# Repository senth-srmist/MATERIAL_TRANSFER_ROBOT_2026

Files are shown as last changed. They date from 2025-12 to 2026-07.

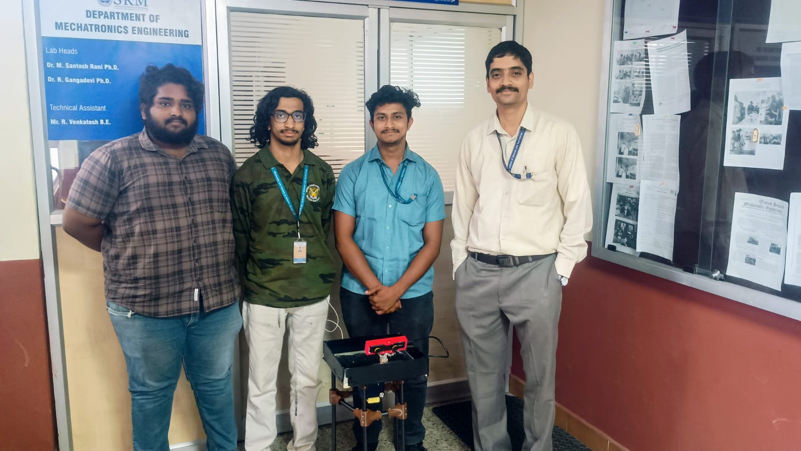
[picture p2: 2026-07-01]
WhatsApp Image 2026-05-07 at 16.34.46.jpeg

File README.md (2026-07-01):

# Floor-Level Material Transfer Mobile Robot

This repository contains the software for the **development of an autonomous floor-level material transfer mobile robot**.
The system is designed to operate within a **single indoor floor environment**, autonomously transporting materials between designated pickup and drop-off points (such as room entrances), while safely coexisting with human activity.

The project aims to establish a **validated core platform for indoor autonomous logistics**, integrating navigation, task handling, and human-aware operation. It serves as a foundation for scalable deployment across larger indoor environments such as offices, academic buildings, and hospitals.

> **Note:** A detailed description of the project motivation, objectives, system architecture, methodology, and deliverables is available in the project presentation:  
> https://github.com/senth-srmist/MATERIAL_TRANSFER_ROBOT_2026/blob/main/REVIEWS/Zeroth_Review/Presentation.pptx

---

## Repository Setup

### 1. Clone the repository

```bash
git clone https://github.com/senth-srmist/MATERIAL_TRANSFER_ROBOT_2026.git
cd MATERIAL_TRANSFER_ROBOT_2026
```

---

### 2. Initialize and update top-level submodules

This repository uses Git submodules for managing external dependencies.

```bash
git submodule update --init --recursive
```

---

## ZED Wrapper Setup

The `zed_wrapper` submodule requires **platform-specific versioning**.
Incorrect versions may lead to build or runtime failures.

### Navigate to the ZED wrapper

```bash
cd CODE/ros_ws/src/zed_wrapper
```

### ZED Wrapper Version Selection

The ZED wrapper **must** be set to version **humble-v4.0.8** for compatibility.

```bash
git checkout humble-v4.2.5
```

---

### Update submodules inside `zed_wrapper`

```bash
git submodule update --init --recursive
```

---

### Verify the selected version

```bash
git describe --tags
```

---

## Updating the Repository

Whenever pulling new changes, ensure submodules are kept in sync:

```bash
git pull
git submodule update --init --recursive
```

---

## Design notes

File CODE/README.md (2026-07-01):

# Material Transfer Robot - Docker Setup

## Prerequisites

> **Note:** Skip step 2 and 3 if your device does not have NVIDIA graphics.

### 1. Check Docker Version

```bash
docker --version
# Must be >= 20.x
```

### 2. Install NVIDIA Container Toolkit

```bash
distribution=$(. /etc/os-release; echo $ID$VERSION_ID)
curl -fsSL https://nvidia.github.io/libnvidia-container/gpgkey | sudo gpg --dearmor -o /usr/share/keyrings/nvidia-container-toolkit-keyring.gpg
curl -s -L "https://nvidia.github.io/libnvidia-container/${distribution}/libnvidia-container.list" -o /tmp/nvidia-container.list
sed -i 's#deb https://#deb [signed-by=/usr/share/keyrings/nvidia-container-toolkit-keyring.gpg] https://#g' /tmp/nvidia-container.list
sudo mv /tmp/nvidia-container.list /etc/apt/sources.list.d/nvidia-container-toolkit.list
sudo apt-get update
sudo apt-get install -y nvidia-container-toolkit
sudo nvidia-ctk runtime configure --runtime=docker
sudo systemctl restart docker
```

### 3. Install ZED udev rules on the host

```bash
sudo mv CODE/99-slabs.rules /etc/udev/rules.d/99-slabs.rules
sudo chmod 644 /etc/udev/rules.d/99-slabs.rules
sudo udevadm control --reload-rules
sudo udevadm trigger
```

## Build Dev Container

> **Note:** The base image is pre-built and hosted on GitHub Container Registry
> (`ghcr.io/tejasmk-tkp/material-transfer-robot-base-{amd64|arm64}:latest`).
> It will be pulled automatically during build — no manual setup needed.

```bash
# amd64 (Laptop)
TARGETARCH=amd64 docker compose build

# arm64 (Jetson)
TARGETARCH=arm64 docker-compose build
```

## Start and Run the Container

```bash
xhost +local:docker
```

### ROS2 Communication Modes

| Mode | Description | Network | Use Case |
| --- | --- | --- | --- |
| local | Localhost only | No | Single-device operation |
| network | Full cross-device DDS | Yes | Multi-device ROS2 (high bandwidth) |
| viz | Throttled remote rviz | Yes | Remote visualization (low bandwidth) |

### Local Mode (Default)

```bash
docker compose up -d

# arm64 (Jetson)
docker-compose -f docker-compose.yml -f docker-compose.arm64.yml up -d
```

### Network Mode

```bash
ROS_MODE=network CYCLONE_INTERFACE_IP=<YOUR_IP> docker compose up -d

# arm64 (Jetson)
ROS_MODE=network CYCLONE_INTERFACE_IP=<YOUR_IP> docker-compose -f docker-compose.yml -f docker-compose.arm64.yml up -d
```

### Viz Mode (Remote RViz)

Run rviz on your laptop with minimal WiFi load. Robot stays local. A bridge forwards selected topics at throttled rates.

**On the Robot (Jetson):**

```bash
CYCLONE_INTERFACE_IP=<YOUR_IP> docker-compose -f docker-compose.yml -f docker-compose.arm64.yml -f docker-compose.viz.yml up -d material-transfer-robot viz-bridge
```

**On the Laptop:**

```bash
CYCLONE_INTERFACE_IP=<YOUR_IP> docker compose -f docker-compose.yml -f docker-compose.viz.yml up viz-laptop
```

RViz auto-launches. Default config: `/workspace/rviz/viz.rviz`

**Custom rviz config:**

```bash
CYCLONE_INTERFACE_IP=<YOUR_IP> RVIZ_CONFIG=/workspace/rviz/nav.rviz docker compose -f docker-compose.yml -f docker-compose.viz.yml up viz-laptop
```

**Customizing topics:** Edit `viz_bridge_config.yaml`, then `docker-compose restart viz-bridge`.

**Stopping:**

```bash
# Laptop
docker compose -f docker-compose.yml -f docker-compose.viz.yml stop viz-laptop

# Robot
docker-compose -f docker-compose.yml -f docker-compose.arm64.yml -f docker-compose.viz.yml down
```

### Access Container

```bash
docker exec -it material-transfer-robot-container bash
```

### Stop Container

```bash
docker compose down
```

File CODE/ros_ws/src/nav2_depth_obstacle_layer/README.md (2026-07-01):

# nav2_depth_obstacle_layer

A Nav2 costmap layer plugin that projects depth image points as obstacles with optional human detection masking. Also provides BehaviorTree nodes for human-aware navigation.

## Overview

### Costmap Layer

Projects depth images onto the costmap as `LETHAL_OBSTACLE`. Points are filtered by height above ground to exclude floor and overhead obstacles.

**Human Detection Masking (Optional):** When enabled with ZED camera messages, regions containing detected humans are excluded from obstacle marking. This allows the BT nodes to handle human encounters (stop and wait) without triggering path replanning.

### BT Nodes

- **HumanBlockingPath**: Condition node that returns SUCCESS when a human is blocking the planned path within `human_stop_distance` of the robot.
- **WaitUntilHumanClears**: Action node that stops the robot and waits until the human moves away, optionally calling a speech service.

## Costmap Layer Parameters

| Parameter | Type | Default | Description |
|---|---|---|---|
| `depth_topic` | string | `/depth/image_rect` | Depth image topic |
| `camera_info_topic` | string | `/depth/camera_info` | Camera info topic |
| `ground_frame` | string | `base_link` | Frame for height calculation |
| `stride` | int | `2` | Pixel stride for processing |
| `obstacle_range` | double | `3.0` | Maximum range in meters |
| `min_obstacle_height` | double | `0.05` | Minimum height above ground (m) |
| `max_obstacle_height` | double | `1.5` | Maximum height above ground (m) |
| `human_mask_enabled` | bool | `false` | Enable human detection masking |
| `human_topic` | string | `""` | Human detection topic (ZED objects) |
| `human_mask_padding` | int | `20` | Padding around human bbox (pixels) |
| `human_persistence` | double | `0.5` | Time to keep human detection (s) |

## BT Node Ports

### HumanBlockingPath

| Port | Type | Default | Description |
|---|---|---|---|
| `path` | input | - | Current navigation path |
| `human_stop_distance` | input | `1.5` | Only stop if human within this distance (m) |
| `path_width` | input | `0.3` | Human must be within this of path (m) |
| `human_topic` | input | `/zed/zed_node/obj_det/objects` | Human detection topic |
| `global_frame` | input | `map` | Global frame |
| `robot_frame` | input | `base_link` | Robot frame |

### WaitUntilHumanClears

| Port | Type | Default | Description |
|---|---|---|---|
| `path` | input | - | Current navigation path |
| `human_stop_distance` | input | `1.5` | Distance threshold (m) |
| `path_width` | input | `0.3` | Path corridor width (m) |
| `human_topic` | input | `/zed/zed_node/obj_det/objects` | Human detection topic |
| `cmd_vel_topic` | input | `/cmd_vel` | Velocity command topic |
| `speak_service` | input | `/speak` | Speech service (empty to disable) |
| `speak_interval` | input | `5.0` | Seconds between announcements |

## Usage

### nav2_params.yaml

```yaml
local_costmap:
  local_costmap:
    ros__parameters:
      plugins: ["depth_obstacle_layer", "inflation_layer"]

      depth_obstacle_layer:
        plugin: "nav2_depth_obstacle_layer::DepthObstacleLayer"
        enabled: true
        depth_topic: "/zed/zed_node/depth/depth_registered"
        camera_info_topic: "/zed/zed_node/depth/camera_info"
        ground_frame: "ground"
        stride: 2
        obstacle_range: 3.0
        min_obstacle_height: 0.05
        max_obstacle_height: 1.5
        human_mask_enabled: true
        human_topic: "/zed/zed_node/obj_det/objects"
        human_mask_padding: 20
        human_persistence: 0.5

bt_navigator:
  ros__parameters:
    plugin_lib_names:
      - nav2_depth_obstacle_layer_bt_nodes
      # ... other plugins

controller_server:
  ros__parameters:
    progress_checker:
      movement_time_allowance: 86400.0  # 24hr - allows indefinite human wait
```

### BT XML

```xml
<ReactiveSequence>
  <Inverter>
    <Sequence>
      <HumanBlockingPath path="{path}" human_stop_distance="1.5"/>
      <WaitUntilHumanClears path="{path}" speak_service="/speak"/>
    </Sequence>
  </Inverter>
  <FollowPath path="{path}"/>
</ReactiveSequence>
```

## Building

```bash
colcon build --packages-select nav2_depth_obstacle_layer
```

The build automatically detects if `zed_msgs` is available. Without it:
- Costmap layer works but human masking is disabled
- BT nodes will not function (return FAILURE)

## Libraries

- `nav2_depth_obstacle_layer` - Costmap layer plugin
- `nav2_depth_obstacle_layer_bt_nodes` - BT nodes plugin

## License

Apache-2.0

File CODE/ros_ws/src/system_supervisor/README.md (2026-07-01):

# System Supervisor

Health monitoring and lifecycle management for the Material Transfer Robot. Manages always-on node monitoring, on-demand navigation stack startup/shutdown, categorized failure recovery, lifecycle-aware shutdown, dependent health checks, and system resource tracking.

## State Machine

```
                    ┌──────────────────────────────────────────────┐
                    │                                              │
  ┌─────────┐   all ready   ┌──────┐  nav_needed  ┌────────────┐ │ all up  ┌────────┐
  │ BOOTING ├──────────────►│ IDLE ├─────────────►│ ACTIVATING ├─┼────────►│ ACTIVE │
  └─────────┘               └──┬───┘              └─────┬───────┘ │        └───┬────┘
                               │  ▲                     │         │            │
                               │  │    abort/fail       │         │  !nav_needed
                               │  └─────────────────────┘         │            │
                               │  ▲                               │  ┌─────────▼──────┐
                               │  └───────────────────────────────┼──┤ DEACTIVATING   │
                               │                                  │  └────────────────┘
                               │          cat3 cascade            │
                               └──────────────────────────────────┘
```

**BOOTING** — Waits for all always-on nodes to come up. Uses progress-based detection. A 60-second boot delay prevents the supervisor from ticking before other nodes have had time to spawn, avoiding CPU/memory pressure on startup. Publishes `/system/ready` when all always-on nodes are RUNNING, then transitions to IDLE.

**IDLE** — All always-on nodes monitored. Waiting for `/system/nav_needed` from the job manager. When a delivery job arrives, transitions to ACTIVATING.

**ACTIVATING** — Starts on-demand nodes sequentially with health gates: ZED → odom_bridge → Nav2 → pid_controller → mission. Each node must pass its health check before the next starts. If any node fails, aborts activation, cleans up, and returns to IDLE.

**ACTIVE** — Full monitoring of all nodes. Categorized failure recovery runs here. Publishes `/system/nav_ready` on entry. Transitions to DEACTIVATING when nav is no longer needed.

**DEACTIVATING** — Shuts down on-demand nodes in reverse order: mission → pid_controller → Nav2 → odom_bridge → ZED. Publishes `/system/nav_shutdown` before stopping nodes. Returns to IDLE.

## Boot Detection

The supervisor uses progress-based detection rather than fixed boot timeouts. Each node tracks a `last_progress` timestamp that resets when milestones are hit:

- **PID found** — Process is at least running (resets stall timer)
- **Heartbeat received** — Node is fully operational (boot complete)

Two thresholds per node:

- `stall_timeout` — No progress for this many seconds means the node is stuck
- `max_boot_timeout` — Absolute safety net regardless of progress

For `pid_only` nodes, PID appearing is sufficient — no heartbeat topic required.

## Node Categories

Each monitored node has a failure category that determines recovery behavior:

**Category 1 (Auto Restart)** — Automatically restarts the node up to `max_restarts` times with a cooldown between attempts. Used for always-on nodes like motors, teleop, and encoders.

**Category 2 (Abort + Restart)** — Sends an e-stop command, then restarts the node. Used for navigation-critical nodes like Nav2, PID controller, and mission controller. If max restarts exhausted, marks system as DEGRADED and disables autonomous operation.

**Category 3 (Cascade Shutdown)** — Sends e-stop, kills all on-demand nodes, publishes nav_shutdown, and returns to IDLE. Used for localization-critical nodes like ZED camera and odom bridge. Losing these means localization is gone — no point keeping Nav2 running.

## Unit Mode

Nodes can be configured as units — atomic groups of processes that are monitored and managed together. If ANY process in a unit dies, the entire unit is restarted.

```yaml
nav2:
  unit: true
  process_names:
    - "controller_server"
    - "planner_server"
    - "bt_navigator"
    - "behavior_server"
    - "smoother_server"
    - "velocity_smoother"
    - "waypoint_follower"
    - "lifecycle_manager_navigation"
```

Unit mode is useful for tightly-coupled node groups like Nav2 where individual node restarts would leave the system in an inconsistent state.

## Lifecycle-Aware Shutdown

For ROS2 lifecycle-managed nodes, the supervisor attempts graceful shutdown before hard-killing processes:

```
Node needs restart
    │
    ├─► Is lifecycle_manager alive?
    │       │
    │       └─► YES: Call shutdown service (deactivate → cleanup → shutdown)
    │               Wait up to lifecycle_timeout seconds
    │
    ├─► Hard kill all processes (SIGTERM → SIGKILL)
    │
    ├─► Cleanup residues (pkill -9 for all process names)
    │
    └─► Verify all processes are dead
```

Configure lifecycle management per node:

```yaml
map_server:
  lifecycle_manager: "lifecycle_manager_map"
  lifecycle_timeout: 2.0
```

The supervisor calls `/{lifecycle_manager}/manage_nodes` with `{command: 2}` (shutdown) to gracefully transition managed nodes through their lifecycle states before hard-killing.

## Dependent Health Checks

When a node restarts, its downstream dependents may be left in a broken state (stale subscriptions, lost connections). The supervisor can automatically check and restart unhealthy dependents:

```yaml
zed:
  dependents: ["odom_bridge"]
  dependent_check_delay: 2.0

map_server:
  dependents: ["nav2"]
  dependent_check_delay: 3.0
```

After a node reaches RUNNING state:
1. Wait `dependent_check_delay` seconds for dependents to react
2. Check each dependent's health (status, heartbeat age)
3. Restart any unhealthy dependents
4. Cascade: restarted dependents will check their own dependents

Race condition guards prevent multiple restart attempts:
- Skip if dependent is already RESTARTING
- Skip if dependent was recently restarted (within cooldown)

## Dynamic Args

Nodes can specify arguments that are resolved at start/restart time by reading from files:

```yaml
map_server:
  start_cmd: ["ros2", "launch", "tile_manager", "map_server.launch.py"]
  dynamic_args:
    - "file:/tmp/current_tile.txt:map:=tile{}.yaml"
```

Format: `file:<filepath>:<format_string>`
- Reads content from `<filepath>`
- Strips whitespace
- Substitutes `{}` with the value
- Appends result to command

Example: If `/tmp/current_tile.txt` contains `3`, the command becomes:
```
ros2 launch tile_manager map_server.launch.py map:=tile3.yaml
```

This enables stateful restarts — the robot continues on the correct tile after a map_server crash.

## Always-On vs On-Demand Nodes

**Always-on** (monitored in all states, launched by robot_bringup):

| Node | Process | Detection | Category | Unit | Dependents |
|---|---|---|---|---|---|
| motors | motor_driver | PID only | Cat 1 | No | — |
| robot_description | robot_state_publisher | PID only | Cat 1 | No | — |
| map_server | map_server, lifecycle_manager_map | PID only | Cat 1 | Yes | nav2 |
| teleop | joy_node | PID only | Cat 1 | No | — |
| encoders | encoder_driver | PID only | Cat 1 | No | — |

**On-demand** (started/stopped by supervisor based on navigation need):

| Node | Process | Detection | Category | Unit | Dependents | Startup Order |
|---|---|---|---|---|---|---|
| zed | zed_wrapper | Topic: `/zed/zed_node/status/heartbeat` | Cat 3 | No | odom_bridge | 1 |
| odom_bridge | odom_base_publisher | Topic: `/odom/base_link` | Cat 3 | No | — | 2 |
| nav2 | (8 processes) | PID only | Cat 2 | Yes | — | 3 |
| pid_controller | pid_controller | PID only | Cat 2 | No | — | 4 |
| mission | mission_service | PID only | Cat 2 | No | — | 5 |

## Topics

### Published

| Topic | Type | QoS | Description |
|---|---|-----|---|
| `/robot_health` | `system_supervisor/RobotHealth` | RELIABLE, TRANSIENT_LOCAL, 1Hz | Full system status: per-node health, CPU, memory, supervisor state |
| `/system/ready` | `std_msgs/Empty` | RELIABLE, TRANSIENT_LOCAL, once | All always-on nodes are up — robot ready to accept jobs |
| `/system/nav_ready` | `std_msgs/Empty` | RELIABLE, TRANSIENT_LOCAL, on event | Nav stack activation complete |
| `/system/nav_shutdown` | `std_msgs/Empty` | RELIABLE, TRANSIENT_LOCAL, on event | Nav stack shutting down |
| `/cmd_vel_estop` | `geometry_msgs/Twist` | RELIABLE, VOLATILE | Emergency stop — zero velocity, routed through twist_mux at highest priority |

### Subscribed

| Topic | Type | QoS | Source |
|---|---|-----|---|
| `/system/nav_needed` | `std_msgs/Bool` | RELIABLE, TRANSIENT_LOCAL | job_manager — true when navigation stack is needed |
| Heartbeat topics | Configured per node | BEST_EFFORT, VOLATILE | Various — dynamic subscriptions from config |

## Messages

### RobotHealth.msg

```
std_msgs/Header header
float32 cpu_percent
uint8 cpu_count
float32 memory_used_mb
float32 memory_total_mb
system_supervisor/NodeHealth[] nodes
uint8 system_state
uint8 supervisor_state
string system_message
bool autonomous_enabled

uint8 NOMINAL=0
uint8 DEGRADED=1
uint8 LOCALIZATION_LOST=2
uint8 EMERGENCY_STOP=3

uint8 SV_BOOTING=0
uint8 SV_IDLE=1
uint8 SV_ACTIVATING=2
uint8 SV_ACTIVE=3
uint8 SV_DEACTIVATING=4
```

### NodeHealth.msg

```
string name
uint8 status
float32 cpu_percent
float32 memory_mb
float32 last_heartbeat_age
uint32 restart_count
uint32 error_count
string last_error
string message

uint8 WAITING=0
uint8 RUNNING=1
uint8 STALE=2
uint8 DEAD=3
uint8 RESTARTING=4
uint8 SHUTDOWN=5
uint8 OFF=6
```

## Configuration

All node definitions are in `config/supervisor_config.yaml`. The supervisor loads this at startup via the `config_file` parameter.

### Config Fields (per node)

| Field | Type | Default | Description |
|---|---|---|---|
| `category` | int | — | Failure category: 1, 2, or 3 |
| `process_name` | string | — | Process name for `pgrep` PID detection (single-process nodes) |
| `heartbeat_topic` | string | — | Topic to subscribe for liveness (omit for pid_only) |
| `heartbeat_msg_type` | string | — | Python message type string, e.g. `nav_msgs.msg.Odometry` |
| `pid_only` | bool | false | If true, PID detection is sufficient — no heartbeat needed |
| `stall_timeout` | float | 15.0 | Seconds without progress before declaring node stuck |
| `max_boot_timeout` | float | 120.0 | Absolute boot time limit |
| `heartbeat_timeout` | float | 3.0 | Seconds without heartbeat before STALE (running nodes) |
| `max_restarts` | int | 3 | Maximum restart attempts before giving up |
| `restart_cooldown` | float | 10.0 | Minimum seconds between restart attempts |
| `start_cmd` | list | — | Command to start the node |
| `dynamic_args` | list | [] | Arguments resolved at runtime from files |

### Unit Mode Fields

| Field | Type | Default | Description |
|---|---|---|---|
| `unit` | bool | false | Treat as atomic group of processes |
| `process_names` | list | [] | All process names in the unit (for monitoring and cleanup) |

### Lifecycle Management Fields

| Field | Type | Default | Description |
|---|---|---|---|
| `lifecycle_manager` | string | — | Name of lifecycle_manager node for graceful shutdown |
| `lifecycle_timeout` | float | 3.0 | Timeout for graceful lifecycle shutdown before hard kill |

### Dependency Management Fields

| Field | Type | Default | Description |
|---|---|---|---|
| `dependents` | list | [] | Node names to health-check after this node restarts |
| `dependent_check_delay` | float | 2.0 | Seconds to wait before checking dependent health |

### On-Demand Node Fields

| Field | Type | Description |
|---|---|---|
| `startup_order` | int | Sequence number for activation (lower starts first) |
| `wait_type` | string | `"topic"` or `"pid"` — what to wait for during activation |

## Resource Monitoring

The supervisor tracks system-wide and per-node resource usage at 0.5 Hz:

- **System CPU** — Read from `/proc/stat`, averaged across all cores
- **System Memory** — Read from `/proc/meminfo` (total and available)
- **Per-node CPU** — Read from `/proc/<pid>/stat` (user + system ticks)
- **Per-node Memory** — RSS from `/proc/<pid>/status`

All values are published in the `/robot_health` message.

## Parameters

| Parameter | Default | Description |
|---|---|---|
| `config_file` | (install path) | Path to supervisor_config.yaml |
| `boot_delay` | 60.0 | Seconds to wait after init before starting health checks |

## Package Structure

```
system_supervisor/
├── config/
│   └── supervisor_config.yaml
├── msg/
│   ├── NodeHealth.msg
│   └── RobotHealth.msg
└── system_supervisor/
    └── system_supervisor.py
```

## Monitoring

```bash
# Watch system health
ros2 topic echo /robot_health

# Wait for robot ready
ros2 topic echo /system/ready --once

# Check supervisor state only
ros2 topic echo /robot_health --field supervisor_state

# Check specific node status
ros2 topic echo /robot_health --field nodes | grep -A5 "name: nav2"
```

## Example Scenarios

### Scenario 1: ZED Camera Crash

```
ZED dies (heartbeat timeout)
    ↓
Category 3 → Cascade shutdown
    ↓
E-stop, kill all on-demand nodes
    ↓
Return to IDLE, await new job
```

### Scenario 2: Map Server Crash (with tile persistence)

```
map_server dies
    ↓
Supervisor reads /tmp/current_tile.txt → "3"
    ↓
Lifecycle shutdown of lifecycle_manager_map
    ↓
Hard kill map_server + lifecycle_manager_map
    ↓
Restart: ros2 launch tile_manager map_server.launch.py map:=tile3.yaml
    ↓
map_server reaches RUNNING
    ↓
Check dependents: nav2
    ↓
nav2 healthy? Continue. Unhealthy? Restart nav2 too.
```

### Scenario 3: Nav2 Controller Server Crash

```
controller_server dies (unit monitors all 8 processes)
    ↓
Unit check fails → entire nav2 unit marked DEAD
    ↓
Category 2 → E-stop + restart
    ↓
Lifecycle shutdown via lifecycle_manager_navigation
    ↓
Hard kill all 8 Nav2 processes
    ↓
Restart: ros2 launch robot_navigation navigation.launch.py
    ↓
All Nav2 nodes come up fresh with clean lifecycle state
```

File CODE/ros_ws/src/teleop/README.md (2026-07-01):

# Teleoperation with Game Controller (ROS 2)

This package enables **manual teleoperation of the robot using a game controller** via ROS 2.

It uses:

* `joy` → to read joystick input
* `teleop_twist_joy` → to convert joystick input into `/cmd_vel`

---
## Step 1: Start the joystick driver

This node reads raw joystick data and publishes it on `/joy`.

```bash
ros2 run joy joy_node
```

### Verify joystick input

In a new terminal:

```bash
ros2 topic echo /joy
```

You should see output like:

```yaml
axes:
- 0.0
- -0.4
buttons:
- 0
- 1
```

If axes/buttons change when you move the controller → **joystick is working**.

---

## Step 2: Start teleop (joystick → velocity)

This node converts `/joy` messages into `/cmd_vel` using a YAML config.

```bash
ros2 run teleop_twist_joy teleop_node \
  --ros-args \
  --params-file src/teleop/config/teleop.yaml
```
---

## Step 3: Verify velocity output

In another terminal:

```bash
ros2 topic echo /cmd_vel
```

Expected behavior:

* Hold the **deadman button** → `/cmd_vel` updates
* Release the deadman → `/cmd_vel` goes to zero
* Left stick forward/back → `linear.x`
* Left stick left/right → `angular.z`

---

## Control Mapping (Xbox-style)

| Control | Action |
| --- | --- |
| Left stick up/down | Forward / Backward (`linear.x`) |
| Left stick left/right | Turn Left / Right (`angular.z`) |
| Right bumper (RB) | Deadman (must be held to move)  |

---

## Useful Debug Commands

Check joystick data:

```bash
ros2 topic echo /joy
```

Check velocity commands:

```bash
ros2 topic echo /cmd_vel
```

Check running nodes:

```bash
ros2 node list
```
---

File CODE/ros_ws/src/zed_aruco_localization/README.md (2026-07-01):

# ZED ArUco Localization

ArUco marker-based localization and evaluation for ZED stereo cameras. Three tools in one package: generate printable markers, localize the camera at runtime, and evaluate marker performance under controlled conditions.

## Quick Start

```bash
# Generate markers
ros2 run zed_aruco_localization aruco_marker_generator --ros-args -p marker_size:=0.07

# Start ZED camera first (required)
ros2 launch zed_wrapper zed_camera.launch.py camera_model:=zedm

# Then run localization
ros2 launch zed_aruco_localization zed_aruco_loc.launch.py camera_model:=zedm

# Or run evaluation
ros2 launch zed_aruco_localization aruco_evaluation.launch.py
ros2 service call /start_evaluation zed_aruco_localization/srv/StartArucoEvaluation \
  "{distance_m: 2.0, angle_deg: 0.0, num_samples: 300}"
```

## Package Structure

```
zed_aruco_localization/
├── CMakeLists.txt
├── config/
│   └── aruco_loc.yaml              # Marker config (auto-generated + manual edits)
├── eval_metrics/
│   └── stats.csv                   # Evaluation results (auto-appended)
├── launch/
│   ├── aruco_evaluation.launch.py  # Evaluation pipeline
│   └── zed_aruco_loc.launch.py     # Runtime localization
├── markers/
│   └── 6x6_1000-0.png             # Generated marker images
├── rviz2/
│   └── aruco.rviz                  # RViz config for visualization
├── src/
│   ├── aruco_marker_eval.cpp       # Evaluation node
│   ├── aruco_marker_generator.cpp  # Marker generator node
│   ├── component/
│   │   ├── include/
│   │   │   ├── aruco.hpp
│   │   │   └── zed_aruco_localization_component.hpp
│   │   └── src/
│   │       ├── aruco.cpp
│   │       └── zed_aruco_localization_component.cpp
│   └── include/
│       └── aruco_loc_visibility_control.hpp
├── srv/
│   └── StartArucoEvaluation.srv
└── videos/
    └── aruco.mp4
```

## Prerequisites

The ZED camera must be running before launching the localization or evaluation nodes. Start it separately:

```bash
ros2 launch zed_wrapper zed_camera.launch.py camera_model:=zedm
```

The localization node subscribes to ZED image topics and calls ZED's `set_pose` service. If ZED is not running, the node will wait for topics and the service to become available.

## Dependencies

- OpenCV 4.x (core, imgproc, calib3d, aruco module)
- [zed-ros2-wrapper](https://github.com/stereolabs/zed-ros2-wrapper) (zed_wrapper, zed_components, zed_msgs)
- image_transport
- tf2, tf2_ros, tf2_geometry_msgs
- yaml-cpp

Supports all ZED camera models: zed, zedm, zed2, zed2i, zedx, zedxm.

## Nodes

### 1. Marker Generator (`aruco_marker_generator`)

Generates printable ArUco markers at real-world physical size and updates `aruco_loc.yaml` with marker definitions.

```bash
ros2 run zed_aruco_localization aruco_marker_generator --ros-args \
  -p marker_count:=3 \
  -p marker_size:=0.07 \
  -p dpi:=300
```

**Parameters:**

| Parameter | Default | Description |
|---|---|---|
| `marker_count` | 1 | Number of markers to generate (IDs: 0 to N-1) |
| `marker_size` | 0.07 | Physical marker size in meters |
| `dpi` | 300 | Print resolution |
| `output_format` | png | Output format (png, jpg, svg) |
| `maximum_distance` | 2.0 | Max detection distance in meters |
| `detection_rate` | 0.5 | Detection frequency in Hz |
| `camera_name` | zed | Camera namespace |
| `world_frame_id` | map | World frame for marker poses |
| `refine_detection` | false | Enable sub-pixel corner refinement |
| `debug_level` | 1 | 0=none, 1=markers, 2=full |

Markers are saved to `markers/` directory. Dictionary: `DICT_6X6_1000`.

> Use **image-magick** to display images at actual size. When printing, ensure scaling is set to 100% / "Actual Size".

### 2. Localization Node (`zed_aruco_loc_node`)

Detects ArUco markers in the ZED camera feed, estimates camera pose relative to known marker positions, and resets the ZED pose in the global map frame via the `set_pose` service. Runs as a composable node in its own container.

**Topics:**

| Direction | Topic | Type | Description |
|---|---|---|---|
| Subscribe | `<cam>/zed_node/rgb/color/rect/image` | sensor_msgs/Image | ZED rectified RGB image |
| Subscribe | `<cam>/zed_node/rgb/color/rect/camera_info` | sensor_msgs/CameraInfo | Camera intrinsics |
| Publish | `<cam>/aruco_node/out/aruco_result` | sensor_msgs/Image | Detection visualization |

**Services (client):**

| Service | Type | Description |
|---|---|---|
| `<cam>/zed_node/set_pose` | zed_msgs/SetPose | Resets ZED camera pose when marker detected |

**TF Broadcasts:**

| Parent Frame | Child Frame | Description |
|---|---|---|
| `<world_frame_id>` | `aruco_marker_<id>` | Known marker positions in world frame |

**Behavior:**
- Only the nearest valid marker within `maximum_distance` is used
- Pose estimation via `estimatePoseSingleMarkers`
- Detection frequency throttled by `detection_rate`
- Requires the `<camera_name>_left_camera_frame` → `<camera_name>_camera_link` TF (published by ZED's state publisher)

**Launch:**

```bash
# ZED must be running first
ros2 launch zed_aruco_localization zed_aruco_loc.launch.py camera_model:=zedm
```

**Launch Arguments:**

| Argument | Default | Description |
|---|---|---|
| `camera_model` | zedm | zed, zedm, zed2, zed2i, zedx, zedxm |
| `camera_name` | zed | Camera namespace |
| `aruco_node_name` | aruco_node | Name of the ArUco node |
| `config_path_aruco` | (package default) | Path to aruco_loc.yaml |
| `rviz` | true | Launch RViz with ArUco config |

### 3. Evaluation Node (`aruco_evaluation`)

Evaluates ArUco marker detection accuracy under controlled conditions. Idle by default — triggered via service call to collect pose statistics at a specific distance and angle.

This node does **not** reset pose, publish TF, or interfere with localization.

**Topics:**

| Direction | Topic | Type | Description |
|---|---|---|---|
| Subscribe | `/zed/zed_node/rgb/image_rect_color` | sensor_msgs/Image | ZED rectified RGB |
| Subscribe | (camera_info from same transport) | sensor_msgs/CameraInfo | Camera intrinsics |

**Services (server):**

| Service | Type | Description |
|---|---|---|
| `/start_evaluation` | StartArucoEvaluation | Start a measurement run |

**Service Request:**

| Field | Type | Description |
|---|---|---|
| `distance_m` | float32 | Physical distance between camera and marker |
| `angle_deg` | float32 | Viewing angle of marker |
| `num_samples` | int32 | Number of frames to process |

**Launch:**

```bash
# ZED must be running first
ros2 launch zed_aruco_localization aruco_evaluation.launch.py
ros2 launch zed_aruco_localization aruco_evaluation.launch.py camera_model:=zedm
```

**Computed Statistics (per run):**
- Mean and standard deviation of x, y, z, yaw
- Detection ratio (detections / attempted frames)
- Results appended to `eval_metrics/stats.csv`

**CSV Columns:**

```
timestamp, marker_size_m, distance_m, angle_deg, samples_collected,
frames_attempted, detection_ratio, mean_x_m, std_x_m, mean_y_m,
std_y_m, mean_z_m, std_z_m, mean_yaw_deg, std_yaw_deg
```

## Configuration

All parameters are loaded from `config/aruco_loc.yaml`. This file is auto-generated by the marker generator but can be edited manually.

```yaml
/**:
  ros__parameters:
    general:
      marker_count: 1
      marker_size: 0.030
      maximum_distance: 2.000
      detection_rate: 0.500
      camera_name: zed
      world_frame_id: map
      refine_detection: false
    debug:
      level: 1                          # 0=none, 1=markers, 2=full
    marker_000:
      aruco_id: 0
      position: [0.000, 0.000, 0.000]  # x, y, z in world frame
      orientation: [0.000, 0.000, 0.000] # roll, pitch, yaw in radians
```

> For every marker, update `position` and `orientation` with respect to the world frame to ensure correct localization. Default values are `[0, 0, 0]`.

## Evaluation Workflow

1. Print marker at target size using the generator
2. Mount marker flat on a wall
3. Place camera at a known distance and angle
4. Start ZED camera
5. Launch the evaluation node
6. Call the evaluation service with distance, angle, and sample count
7. Wait for completion — results are logged to terminal and CSV
8. Move to next configuration and repeat

Each service call produces one row in `eval_metrics/stats.csv`. The file is append-only, never overwritten.

## Integration Status

The localization node is planned for integration into the robot's production runtime via the system supervisor. Currently it runs standalone for testing and evaluation. Future integration will allow the supervisor to trigger ArUco-based relocalization on demand, for example after a ZED camera crash or localization drift.

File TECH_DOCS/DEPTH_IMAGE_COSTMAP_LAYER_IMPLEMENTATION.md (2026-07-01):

# DepthImageCostmapLayer Implementation Guide

## Background

Nav2's built-in `ObstacleLayer` in ROS2 Humble only supports `PointCloud2` and `LaserScan` — it does **not** support `DepthImage` directly. Our ZED camera produces a sparse point cloud even at maximum settings (VGA + COMPACT mode), but the depth map is dense and high quality.

Rather than using `depth_image_proc` to convert depth → PointCloud2 (adding ~50-100MB RAM and an extra node), we're building a custom Nav2 costmap layer plugin that directly consumes depth images.

### Why Custom Plugin?

| Approach | Memory | Latency | Control |
|---|---|---|---|
| `depth_image_proc` → ObstacleLayer | +50-100MB | Extra hop | None |
| **Custom DepthImageCostmapLayer** | Zero extra | Direct | Full (sampling, filtering) |

---

## Architecture

```
ZED Camera
    │
    ├── /zed/zed_node/depth/depth_registered (sensor_msgs/Image)
    │                           │
    │                           ▼
    │                   DepthImageCostmapLayer
    │                   ├── Subscribes to depth image
    │                   ├── Subscribes to obj_det/objects (human bboxes)
    │                   ├── MASKS OUT pixels inside human bounding boxes ◄── CRITICAL
    │                   ├── Samples remaining pixels at configurable stride
    │                   ├── Projects to 3D → transforms to map frame
    │                   └── Marks obstacles → Nav2 REPLANS AROUND them
    │
    ├── /zed/zed_node/depth/camera_info (sensor_msgs/CameraInfo)
    │
    └── /zed/zed_node/obj_det/objects (zed_msgs/ObjectsStamped)
                            │
                            ├──────────────────────────────────┐
                            │                                  │
                            ▼                                  ▼
                    HumanCostmapLayer                   DepthImageCostmapLayer
                    (marks humans)                      (uses bboxes to EXCLUDE humans)
                            │                                  │
                            ▼                                  ▼
                    BT: HumanBlockingPath              Nav2 Controller
                    → STOP + RAISE ALARM               → REPLAN + NAVIGATE
```

### Key Design: Separation of Concerns

| Obstacle Type | Detected By | Handled By | Nav2 Behavior |
|---|---|---|---|
| **Humans** | ZED obj_det | `HumanCostmapLayer` + BT | **STOP + ALARM** |
| **Everything else** | Depth image (masked) | `DepthImageCostmapLayer` | **REPLAN + NAVIGATE** |

**Why mask humans in depth layer?**
- If both layers mark humans → Nav2 might try to replan around a human
- We want humans to trigger STOP, not replanning
- Masking ensures clean separation of behavior

---

## Package Location

Add to existing `human_detection` package (or create new `depth_costmap_layer` package):

```
ros_ws/src/human_detection/
├── include/human_detection/
│   ├── human_costmap_layer.hpp       # Existing
│   └── depth_image_costmap_layer.hpp # NEW
├── src/
│   ├── human_costmap_layer.cpp       # Existing
│   └── depth_image_costmap_layer.cpp # NEW
├── human_costmap_layer_plugin.xml    # UPDATE (add new plugin)
├── CMakeLists.txt                    # UPDATE
└── package.xml                       # UPDATE (add image_geometry)
```

---

## Dependencies

Add to `package.xml`:

```xml
<depend>image_geometry</depend>
<depend>sensor_msgs</depend>
<depend>cv_bridge</depend>
```

Add to `CMakeLists.txt`:

```cmake
find_package(image_geometry REQUIRED)
find_package(sensor_msgs REQUIRED)
find_package(cv_bridge REQUIRED)

# Add to existing library or create new one
add_library(depth_image_costmap_layer SHARED
  src/depth_image_costmap_layer.cpp
)

ament_target_dependencies(depth_image_costmap_layer
  rclcpp
  nav2_costmap_2d
  pluginlib
  tf2_ros
  tf2_geometry_msgs
  geometry_msgs
  sensor_msgs
  image_geometry
  cv_bridge
)

pluginlib_export_plugin_description_file(nav2_costmap_2d depth_costmap_layer_plugin.xml)
```

---

## Header File

**`include/human_detection/depth_image_costmap_layer.hpp`**

```cpp
#ifndef DEPTH_IMAGE_COSTMAP_LAYER_HPP_
#define DEPTH_IMAGE_COSTMAP_LAYER_HPP_

#include "nav2_costmap_2d/layer.hpp"
#include "nav2_costmap_2d/layered_costmap.hpp"
#include "rclcpp/rclcpp.hpp"
#include "sensor_msgs/msg/image.hpp"
#include "sensor_msgs/msg/camera_info.hpp"
#include "image_geometry/pinhole_camera_model.h"
#include "tf2_ros/buffer.h"
#include "tf2_geometry_msgs/tf2_geometry_msgs.hpp"
#include "geometry_msgs/msg/point_stamped.hpp"
#include "zed_msgs/msg/objects_stamped.hpp"  // For human detection masking

#include <mutex>
#include <vector>
#include <string>

namespace human_detection
{

/**
 * @brief Nav2 costmap layer that directly consumes depth images
 * 
 * This plugin bypasses the need for PointCloud2 conversion by:
 * 1. Subscribing to depth image + camera_info
 * 2. Subscribing to ZED object detections to MASK OUT humans
 * 3. Sampling pixels at configurable stride (for performance)
 * 4. Skipping pixels inside human bounding boxes
 * 5. Projecting remaining pixels to 3D using camera intrinsics
 * 6. Transforming to global frame
 * 7. Marking/clearing costmap cells
 * 
 * IMPORTANT: Humans are handled by HumanCostmapLayer with STOP+ALARM behavior.
 * This layer handles all OTHER obstacles with AVOID+NAVIGATE behavior.
 * We must NOT mark humans here or Nav2 will try to replan around them.
 */
class DepthImageCostmapLayer : public nav2_costmap_2d::Layer
{
public:
  DepthImageCostmapLayer();
  virtual ~DepthImageCostmapLayer();

  // Nav2 Layer interface
  virtual void onInitialize() override;
  virtual void updateBounds(
    double robot_x, double robot_y, double robot_yaw,
    double * min_x, double * min_y,
    double * max_x, double * max_y) override;
  virtual void updateCosts(
    nav2_costmap_2d::Costmap2D & master_grid,
    int min_i, int min_j,
    int max_i, int max_j) override;
  virtual void reset() override;
  virtual bool isClearable() override;

private:
  // Callbacks
  void depthCallback(const sensor_msgs::msg::Image::SharedPtr msg);
  void cameraInfoCallback(const sensor_msgs::msg::CameraInfo::SharedPtr msg);
  void objectsCallback(const zed_msgs::msg::ObjectsStamped::SharedPtr msg);

  // Processing
  void processDepthImage(const sensor_msgs::msg::Image::SharedPtr & depth_msg);
  bool transformToGlobalFrame(
    double & x, double & y, double & z,
    const std::string & source_frame,
    const rclcpp::Time & stamp);
  
  // Human masking
  bool isPixelInsideHumanBbox(int u, int v) const;

  // ROS subscriptions
  rclcpp::Subscription<sensor_msgs::msg::Image>::SharedPtr depth_sub_;
  rclcpp::Subscription<sensor_msgs::msg::CameraInfo>::SharedPtr camera_info_sub_;
  rclcpp::Subscription<zed_msgs::msg::ObjectsStamped>::SharedPtr objects_sub_;

  // Camera model (from image_geometry)
  image_geometry::PinholeCameraModel camera_model_;
  bool camera_model_initialized_;
  std::mutex camera_model_mutex_;

  // Human bounding boxes (2D pixel coordinates) - for masking
  struct HumanBbox
  {
    int u_min, u_max;  // Pixel columns
    int v_min, v_max;  // Pixel rows
  };
  std::vector<HumanBbox> human_bboxes_;
  std::mutex human_bboxes_mutex_;
  rclcpp::Time last_objects_time_;
  double human_bbox_persistence_;  // How long to keep human masks valid

  // Obstacle storage
  struct Obstacle
  {
    double x;  // Global frame
    double y;  // Global frame
    double z;  // Global frame (for height filtering)
  };
  std::vector<Obstacle> obstacles_;
  std::mutex obstacles_mutex_;

  // Parameters
  std::string depth_topic_;
  std::string camera_info_topic_;
  std::string objects_topic_;       // ZED object detections
  std::string sensor_frame_;
  int sample_stride_;               // Process every Nth pixel (performance vs density)
  double min_obstacle_height_;      // Relative to ground (filter floor)
  double max_obstacle_height_;      // Filter ceiling/high objects
  double min_range_;                // Minimum depth to consider
  double max_range_;                // Maximum depth to consider
  double obstacle_persistence_;     // How long obstacles persist (seconds)
  bool marking_;                    // Mark obstacles
  bool clearing_;                   // Clear free space via raytrace
  bool mask_humans_;                // Whether to mask out human detections
  int human_bbox_padding_;          // Extra pixels around human bbox (safety margin)

  // Timing
  rclcpp::Time last_depth_time_;

}  // namespace human_detection

#endif  // DEPTH_IMAGE_COSTMAP_LAYER_HPP_
```

---

## Source File

**`src/depth_image_costmap_layer.cpp`**

```cpp
#include "human_detection/depth_image_costmap_layer.hpp"
#include "pluginlib/class_list_macros.hpp"
#include "nav2_costmap_2d/costmap_math.hpp"
#include <cv_bridge/cv_bridge.h>
#include <cmath>
#include <limits>

using nav2_costmap_2d::LETHAL_OBSTACLE;
using nav2_costmap_2d::FREE_SPACE;
using nav2_costmap_2d::NO_INFORMATION;

namespace human_detection
{

DepthImageCostmapLayer::DepthImageCostmapLayer()
: camera_model_initialized_(false)
{
}

DepthImageCostmapLayer::~DepthImageCostmapLayer()
{
}

void DepthImageCostmapLayer::onInitialize()
{
  auto node = node_.lock();
  if (!node) {
    throw std::runtime_error("Failed to lock node");
  }

  // Declare parameters
  declareParameter("depth_topic", rclcpp::ParameterValue("/zed/zed_node/depth/depth_registered"));
  declareParameter("camera_info_topic", rclcpp::ParameterValue("/zed/zed_node/depth/camera_info"));
  declareParameter("objects_topic", rclcpp::ParameterValue("/zed/zed_node/obj_det/objects"));
  declareParameter("sensor_frame", rclcpp::ParameterValue("zed_left_camera_optical_frame"));
  declareParameter("sample_stride", rclcpp::ParameterValue(4));  // Every 4th pixel
  declareParameter("min_obstacle_height", rclcpp::ParameterValue(0.1));
  declareParameter("max_obstacle_height", rclcpp::ParameterValue(1.5));
  declareParameter("min_range", rclcpp::ParameterValue(0.2));
  declareParameter("max_range", rclcpp::ParameterValue(3.0));
  declareParameter("obstacle_persistence", rclcpp::ParameterValue(0.5));
  declareParameter("marking", rclcpp::ParameterValue(true));
  declareParameter("clearing", rclcpp::ParameterValue(true));
  declareParameter("mask_humans", rclcpp::ParameterValue(true));  // IMPORTANT: Default ON
  declareParameter("human_bbox_padding", rclcpp::ParameterValue(20));  // 20 pixel margin
  declareParameter("human_bbox_persistence", rclcpp::ParameterValue(0.3));  // 300ms

  // Get parameters
  node->get_parameter(name_ + ".depth_topic", depth_topic_);
  node->get_parameter(name_ + ".camera_info_topic", camera_info_topic_);
  node->get_parameter(name_ + ".objects_topic", objects_topic_);
  node->get_parameter(name_ + ".sensor_frame", sensor_frame_);
  node->get_parameter(name_ + ".sample_stride", sample_stride_);
  node->get_parameter(name_ + ".min_obstacle_height", min_obstacle_height_);
  node->get_parameter(name_ + ".max_obstacle_height", max_obstacle_height_);
  node->get_parameter(name_ + ".min_range", min_range_);
  node->get_parameter(name_ + ".max_range", max_range_);
  node->get_parameter(name_ + ".obstacle_persistence", obstacle_persistence_);
  node->get_parameter(name_ + ".marking", marking_);
  node->get_parameter(name_ + ".clearing", clearing_);
  node->get_parameter(name_ + ".mask_humans", mask_humans_);
  node->get_parameter(name_ + ".human_bbox_padding", human_bbox_padding_);
  node->get_parameter(name_ + ".human_bbox_persistence", human_bbox_persistence_);

  // Clamp stride to reasonable range
  sample_stride_ = std::max(1, std::min(sample_stride_, 16));

  // Subscribe to camera info first (needed for projection)
  camera_info_sub_ = node->create_subscription<sensor_msgs::msg::CameraInfo>(
    camera_info_topic_,
    rclcpp::SensorDataQoS(),
    std::bind(&DepthImageCostmapLayer::cameraInfoCallback, this, std::placeholders::_1));

  // Subscribe to depth image
  depth_sub_ = node->create_subscription<sensor_msgs::msg::Image>(
    depth_topic_,
    rclcpp::SensorDataQoS(),
    std::bind(&DepthImageCostmapLayer::depthCallback, this, std::placeholders::_1));

  // Subscribe to ZED object detections (for human masking)
  if (mask_humans_) {
    objects_sub_ = node->create_subscription<zed_msgs::msg::ObjectsStamped>(
      objects_topic_,
      rclcpp::SensorDataQoS(),
      std::bind(&DepthImageCostmapLayer::objectsCallback, this, std::placeholders::_1));
    
    RCLCPP_INFO(node->get_logger(),
      "Human masking ENABLED: pixels inside human bounding boxes will be skipped");
  }

  current_ = true;
  enabled_ = true;

  RCLCPP_INFO(node->get_logger(),
    "DepthImageCostmapLayer initialized: depth=%s, stride=%d, range=[%.2f, %.2f], "
    "height=[%.2f, %.2f], mask_humans=%s",
    depth_topic_.c_str(), sample_stride_, min_range_, max_range_,
    min_obstacle_height_, max_obstacle_height_,
    mask_humans_ ? "true" : "false");
}

void DepthImageCostmapLayer::cameraInfoCallback(
  const sensor_msgs::msg::CameraInfo::SharedPtr msg)
{
  std::lock_guard<std::mutex> lock(camera_model_mutex_);
  camera_model_.fromCameraInfo(msg);
  camera_model_initialized_ = true;
}

void DepthImageCostmapLayer::objectsCallback(
  const zed_msgs::msg::ObjectsStamped::SharedPtr msg)
{
  auto node = node_.lock();
  if (!node) return;

  std::vector<HumanBbox> new_bboxes;

  for (const auto & obj : msg->objects) {
    // ZED SDK: Person class is typically label_id 0
    // Check your ZED config - mc_people should be enabled
    // The label_id for PERSON may vary, commonly 0 or check zed_msgs
    
    // Skip non-person objects
    // Note: Adjust this check based on your ZED SDK version
    // Some versions use string label, others use label_id
    if (obj.label_id != 0) {  // 0 = PERSON in ZED SDK
      continue;
    }

    // ZED provides 2D bounding box in image coordinates
    // bounding_box_2d is typically [4][2] = 4 corners, each with (u, v)
    // We need min/max of u and v
    
    if (obj.bounding_box_2d.corners.size() < 4) {
      continue;
    }

    int u_min = std::numeric_limits<int>::max();
    int u_max = std::numeric_limits<int>::min();
    int v_min = std::numeric_limits<int>::max();
    int v_max = std::numeric_limits<int>::min();

    for (const auto & corner : obj.bounding_box_2d.corners) {
      int u = static_cast<int>(corner.kp[0]);
      int v = static_cast<int>(corner.kp[1]);
      u_min = std::min(u_min, u);
      u_max = std::max(u_max, u);
      v_min = std::min(v_min, v);
      v_max = std::max(v_max, v);
    }

    // Add padding for safety margin
    u_min -= human_bbox_padding_;
    u_max += human_bbox_padding_;
    v_min -= human_bbox_padding_;
    v_max += human_bbox_padding_;

    new_bboxes.push_back({u_min, u_max, v_min, v_max});
  }

  // Update human bboxes (thread-safe)
  {
    std::lock_guard<std::mutex> lock(human_bboxes_mutex_);
    human_bboxes_ = std::move(new_bboxes);
    last_objects_time_ = msg->header.stamp;
  }

  if (!new_bboxes.empty()) {
    RCLCPP_DEBUG(node->get_logger(),
      "Updated %zu human bounding boxes for masking", new_bboxes.size());
  }
}

bool DepthImageCostmapLayer::isPixelInsideHumanBbox(int u, int v) const
{
  // Note: Called with human_bboxes_mutex_ already locked by caller
  for (const auto & bbox : human_bboxes_) {
    if (u >= bbox.u_min && u <= bbox.u_max &&
        v >= bbox.v_min && v <= bbox.v_max)
    {
      return true;
    }
  }
  return false;
}

void DepthImageCostmapLayer::depthCallback(
  const sensor_msgs::msg::Image::SharedPtr msg)
{
  {
    std::lock_guard<std::mutex> lock(camera_model_mutex_);
    if (!camera_model_initialized_) {
      return;  // Wait for camera info
    }
  }

  processDepthImage(msg);
}

void DepthImageCostmapLayer::processDepthImage(
  const sensor_msgs::msg::Image::SharedPtr & depth_msg)
{
  auto node = node_.lock();
  if (!node) return;

  // Convert to OpenCV
  cv_bridge::CvImageConstPtr cv_ptr;
  try {
    // ZED publishes 32FC1 depth images (meters)
    cv_ptr = cv_bridge::toCvShare(depth_msg, sensor_msgs::image_encodings::TYPE_32FC1);
  } catch (const cv_bridge::Exception & e) {
    RCLCPP_ERROR(node->get_logger(), "cv_bridge exception: %s", e.what());
    return;
  }

  const cv::Mat & depth_image = cv_ptr->image;
  const int width = depth_image.cols;
  const int height = depth_image.rows;

  std::vector<Obstacle> new_obstacles;
  new_obstacles.reserve((width / sample_stride_) * (height / sample_stride_));

  // Get camera model (thread-safe copy)
  image_geometry::PinholeCameraModel model;
  {
    std::lock_guard<std::mutex> lock(camera_model_mutex_);
    model = camera_model_;
  }

  // Get human bboxes (thread-safe copy) and check freshness
  std::vector<HumanBbox> current_human_bboxes;
  bool human_bboxes_valid = false;
  if (mask_humans_) {
    std::lock_guard<std::mutex> lock(human_bboxes_mutex_);
    double bbox_age = (node->now() - last_objects_time_).seconds();
    if (bbox_age < human_bbox_persistence_) {
      current_human_bboxes = human_bboxes_;
      human_bboxes_valid = true;
    }
  }

  int skipped_human_pixels = 0;  // For debug logging

  // Sample pixels at stride
  for (int v = 0; v < height; v += sample_stride_) {
    for (int u = 0; u < width; u += sample_stride_) {
      
      // ============================================================
      // CRITICAL: Skip pixels inside human bounding boxes
      // Humans are handled by HumanCostmapLayer (STOP + ALARM)
      // We only handle non-human obstacles (AVOID + NAVIGATE)
      // ============================================================
      if (mask_humans_ && human_bboxes_valid) {
        bool inside_human = false;
        for (const auto & bbox : current_human_bboxes) {
          if (u >= bbox.u_min && u <= bbox.u_max &&
              v >= bbox.v_min && v <= bbox.v_max)
          {
            inside_human = true;
            break;
          }
        }
        if (inside_human) {
          skipped_human_pixels++;
          continue;  // Skip this pixel - human region
        }
      }

      float depth = depth_image.at<float>(v, u);

      // Filter invalid/out-of-range depths
      if (!std::isfinite(depth) || depth < min_range_ || depth > max_range_) {
        continue;
      }

      // Project pixel to 3D ray using camera model
      // cv::Point2d(u, v) -> 3D unit ray
      cv::Point3d ray = model.projectPixelTo3dRay(cv::Point2d(u, v));

      // Scale ray by depth to get 3D point in camera optical frame
      // Note: In optical frame, Z is forward, X is right, Y is down
      double cam_x = ray.x * depth;
      double cam_y = ray.y * depth;
      double cam_z = ray.z * depth;  // This equals depth for optical frame

      // Transform to global frame
      double global_x = cam_x;
      double global_y = cam_y;
      double global_z = cam_z;

      if (!transformToGlobalFrame(global_x, global_y, global_z,
          depth_msg->header.frame_id, depth_msg->header.stamp))
      {
        continue;  // TF not available
      }

      // Height filtering (global_z is height above ground after transform)
      if (global_z < min_obstacle_height_ || global_z > max_obstacle_height_) {
        continue;
      }

      new_obstacles.push_back({global_x, global_y, global_z});
    }
  }

  if (skipped_human_pixels > 0) {
    RCLCPP_DEBUG(node->get_logger(),
      "Skipped %d pixels inside human bounding boxes", skipped_human_pixels);
  }

  // Update obstacle list (thread-safe)
  {
    std::lock_guard<std::mutex> lock(obstacles_mutex_);
    obstacles_ = std::move(new_obstacles);
    last_depth_time_ = depth_msg->header.stamp;
  }
}

bool DepthImageCostmapLayer::transformToGlobalFrame(
  double & x, double & y, double & z,
  const std::string & source_frame,
  const rclcpp::Time & stamp)
{
  auto node = node_.lock();
  if (!node) return false;

  geometry_msgs::msg::PointStamped in_point, out_point;
  in_point.header.frame_id = source_frame;
  in_point.header.stamp = stamp;
  in_point.point.x = x;
  in_point.point.y = y;
  in_point.point.z = z;

  try {
    // Transform to global frame (typically "map" or "odom")
    out_point = tf_->transform(
      in_point,
      layered_costmap_->getGlobalFrameID(),
      tf2::durationFromSec(0.1));

    x = out_point.point.x;
    y = out_point.point.y;
    z = out_point.point.z;
    return true;
  } catch (const tf2::TransformException & ex) {
    RCLCPP_WARN_THROTTLE(
      node->get_logger(),
      *node->get_clock(),
      1000,
      "TF transform failed: %s", ex.what());
    return false;
  }
}

void DepthImageCostmapLayer::updateBounds(
  double /*robot_x*/, double /*robot_y*/, double /*robot_yaw*/,
  double * min_x, double * min_y,
  double * max_x, double * max_y)
{
  std::lock_guard<std::mutex> lock(obstacles_mutex_);

  // Check for stale data
  auto node = node_.lock();
  if (node) {
    double age = (node->now() - last_depth_time_).seconds();
    if (age > obstacle_persistence_) {
      obstacles_.clear();
      return;  // Data too old, don't expand bounds
    }
  }

  // Expand bounds to include all obstacles
  for (const auto & obs : obstacles_) {
    *min_x = std::min(*min_x, obs.x);
    *min_y = std::min(*min_y, obs.y);
    *max_x = std::max(*max_x, obs.x);
    *max_y = std::max(*max_y, obs.y);
  }
}

void DepthImageCostmapLayer::updateCosts(
  nav2_costmap_2d::Costmap2D & master_grid,
  int min_i, int min_j,
  int max_i, int max_j)
{
  if (!enabled_) return;

  std::lock_guard<std::mutex> lock(obstacles_mutex_);

  // Mark obstacle cells
  if (marking_) {
    for (const auto & obs : obstacles_) {
      unsigned int mx, my;
      if (master_grid.worldToMap(obs.x, obs.y, mx, my)) {
        // Check bounds
        int ix = static_cast<int>(mx);
        int iy = static_cast<int>(my);
        if (ix >= min_i && ix < max_i && iy >= min_j && iy < max_j) {
          master_grid.setCost(mx, my, LETHAL_OBSTACLE);
        }
      }
    }
  }

  // Note: Clearing (raytracing) is more complex and optional
  // For now, we rely on the existing obstacle layer's clearing
  // or implement a simple clearing strategy if needed
}

void DepthImageCostmapLayer::reset()
{
  std::lock_guard<std::mutex> lock(obstacles_mutex_);
  obstacles_.clear();
  current_ = true;
}

bool DepthImageCostmapLayer::isClearable()
{
  return true;
}

}  // namespace human_detection

// Register the plugin
PLUGINLIB_EXPORT_CLASS(
  human_detection::DepthImageCostmapLayer,
  nav2_costmap_2d::Layer)
```

---

## Plugin XML

**`depth_costmap_layer_plugin.xml`** (or add to existing `human_costmap_layer_plugin.xml`):

```xml
<library path="depth_image_costmap_layer">
  <class name="human_detection/DepthImageCostmapLayer"
         type="human_detection::DepthImageCostmapLayer"
         base_class_type="nav2_costmap_2d::Layer">
    <description>
      Costmap layer that directly consumes depth images without PointCloud2 conversion.
      Samples depth pixels at configurable stride, projects to 3D, and marks obstacles.
    </description>
  </class>
</library>
```

---

## Nav2 Configuration

**Add to `nav2_params.yaml`:**

```yaml
local_costmap:
  local_costmap:
    ros__parameters:
      plugins: ["depth_layer", "human_layer", "inflation_layer"]
      
      depth_layer:
        plugin: "human_detection/DepthImageCostmapLayer"
        enabled: true
        depth_topic: "/zed/zed_node/depth/depth_registered"
        camera_info_topic: "/zed/zed_node/depth/camera_info"
        objects_topic: "/zed/zed_node/obj_det/objects"  # For human masking
        sensor_frame: "zed_left_camera_optical_frame"
        sample_stride: 4              # Every 4th pixel (VGA 672x376 → ~16k points)
        min_obstacle_height: 0.1      # 10cm above ground (filter floor)
        max_obstacle_height: 1.5      # 1.5m (filter ceiling)
        min_range: 0.2                # ZED-M minimum
        max_range: 3.0                # Effective range for indoor nav
        obstacle_persistence: 0.5     # Clear after 500ms
        marking: true
        clearing: false               # Let inflation handle clearing
        # Human masking config (CRITICAL for correct behavior)
        mask_humans: true             # Skip pixels inside human bboxes
        human_bbox_padding: 20        # Extra 20 pixel margin around humans
        human_bbox_persistence: 0.3   # Keep masks valid for 300ms

      human_layer:
        plugin: "human_detection/HumanCostmapLayer"
        # ... existing config ...
        # This layer marks humans -> triggers STOP + ALARM via BT

      inflation_layer:
        plugin: "nav2_costmap_2d::InflationLayer"
        # ... existing config ...
```

### Behavior Summary

| Layer | Handles | Nav2 Behavior |
|---|---|---|
| `depth_layer` | Walls, furniture, objects (NOT humans) | Replan around |
| `human_layer` | Humans only | Stop + alarm (via BT) |
| `inflation_layer` | Buffer around all obstacles | Safety margin |
```

---

## Testing Checklist

### Phase 1: Build & Load

```bash
# Build
cd /workspace/ros_ws
colcon build --packages-select human_detection

# Source
source install/setup.bash

# Verify plugin is registered
ros2 pkg prefix human_detection
find $(ros2 pkg prefix human_detection) -name "*.so" | xargs -I{} nm -C {} | grep DepthImage
```

### Phase 2: Runtime Verification

```bash
# Launch robot with nav2
ros2 launch robot_bringup robot_bringup.launch.py

# Check if layer loaded
ros2 topic echo /local_costmap/costmap --once

# Monitor for errors
ros2 topic echo /rosout | grep -i depth
```

### Phase 3: Human Masking Verification (CRITICAL)

This phase ensures humans are NOT marked by the depth layer.

```bash
# 1. Check human detections are coming in
ros2 topic echo /zed/zed_node/obj_det/objects --field objects

# 2. Monitor debug output (temporarily set log level to DEBUG)
ros2 param set /local_costmap/local_costmap depth_layer.log_level DEBUG

# 3. Look for "Skipped X pixels inside human bounding boxes" messages
ros2 topic echo /rosout | grep -i "Skipped.*human"
```

**Manual Test:**
1. Stand in front of robot (you should be detected as human)
2. Observe costmap in RViz:
   - `HumanCostmapLayer` should show obstacle at your position (red/lethal)
   - `DepthImageCostmapLayer` should have a "hole" where you are
3. Nav2 should trigger STOP + ALARM, NOT try to replan around you

**If both layers mark you:**
- Check `mask_humans: true` in config
- Verify `/zed/zed_node/obj_det/objects` is publishing person detections
- Check `human_bbox_persistence` isn't too short

### Phase 4: Visualization

```bash
# In RViz, add:
# - /local_costmap/costmap (Map display)
# - /zed/zed_node/depth/depth_registered (Image display)

# Compare depth image coverage vs costmap marks
```

### Phase 5: Performance Tuning

| Parameter | Effect | Tune For |
|---|---|---|
| `sample_stride` | ↑ = fewer points, faster | Jetson: try 4-8 |
| `obstacle_persistence` | ↑ = obstacles linger | Slow robot: 0.5-1.0s |
| `max_range` | ↑ = more points | Indoor: 3m is usually enough |
| `human_bbox_padding` | ↑ = larger masked area | Increase if human edges leak |
| `human_bbox_persistence` | ↑ = masks stay valid longer | Increase if detection drops frames |

---

## Stride Calculation

At VGA resolution (672×376) with stride 4:

```
Points per frame = (672/4) * (376/4) = 168 * 94 = ~15,792 points
```

Compare to ZED's COMPACT point cloud which gives ~2,000-5,000 points. This is 3-8x denser while still being efficient.

---

## Common Issues

### 1. "TF transform failed"

The depth image frame (`zed_left_camera_optical_frame`) must be in the TF tree. Ensure ZED is publishing TF or your URDF has the correct frames.

### 2. "cv_bridge exception"

ZED publishes 32FC1 depth. If you see this error, check the depth image encoding:

```bash
ros2 topic echo /zed/zed_node/depth/depth_registered --field encoding
```

### 3. Obstacles not appearing

- Check `min_obstacle_height` / `max_obstacle_height` — are they correct for your camera mount?
- Verify TF: is `zed_left_camera_optical_frame` → `map` working?
- Check depth image is publishing at expected rate

### 4. Performance issues

- Increase `sample_stride` (e.g., 4 → 8)
- Decrease `max_range` (e.g., 3.0 → 2.0)
- Run `htop` and monitor CPU usage

### 5. Humans being marked by depth layer (CRITICAL BUG)

**Symptom:** Nav2 tries to replan around humans instead of stopping.

**This breaks the intended behavior:** humans should trigger STOP + ALARM, not replanning.

**Debug checklist:**
```bash
# 1. Is mask_humans enabled?
ros2 param get /local_costmap/local_costmap depth_layer.mask_humans

# 2. Is object detection publishing?
ros2 topic hz /zed/zed_node/obj_det/objects

# 3. Are you detected as a person?
ros2 topic echo /zed/zed_node/obj_det/objects --field objects
# Look for label_id: 0 (PERSON)

# 4. Check debug logs
ros2 topic echo /rosout | grep -i "human bounding boxes"
```

**Fixes:**
- Set `mask_humans: true` in nav2_params.yaml
- Increase `human_bbox_persistence` to 0.5s if detections are dropping frames
- Increase `human_bbox_padding` to 30-40 if edges leak through
- Ensure ZED config has `mc_people: true`

### 6. Human walks through without robot stopping

This is a `HumanCostmapLayer` or BT issue, not `DepthImageCostmapLayer`:
- Check ZED object detection: `mc_people: true` in zedm.yaml
- Verify `HumanBlockingPath` BT node is in your behavior tree
- Check human detection confidence threshold

---

## Future Improvements

1. **Clearing via raytracing**: Implement proper ray clearing to mark free space
2. **Confidence filtering**: Use ZED confidence map to reject low-confidence depths
3. **Temporal filtering**: Average multiple frames to reduce noise
4. **Region of interest**: Only process center portion of image (ignore edges)

---

## References

- [Nav2 Costmap2D Plugins](https://navigation.ros.org/plugins/index.html)
- [image_geometry::PinholeCameraModel](http://docs.ros.org/en/noetic/api/image_geometry/html/c++/classimage__geometry_1_1PinholeCameraModel.html)
- [HumanCostmapLayer implementation](../human_costmap_layer.cpp) — reference for plugin structure

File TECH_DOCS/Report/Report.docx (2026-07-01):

DESIGN AND DEVELOPMENT OF Floor Level Material Transfer Robot

21MHP401L - MAJOR PROJECT REPORT

Submitted by

Lalithesh K (RA2211038010007)

Tejas M K (RA2211038010012)

Preetham M (RA2211038010046)

(Batch No.: MHRP02)

Under the guidance of

Dr. R. Senthilnathan M.E., Ph.D.

(Professor, Department of Mechatronics Engineering)

In Partial Fulfilment for the Degree

of

BACHELOR OF TECHNOLOGY

in

MECHATRONICS ENGINEERING (ROBOTICS)

of

COLLEGE OF ENGINEERING & TECHNOLOGY

SRM INSTITUTE OF SCIENCE AND TECHNOLOGY

May 2026

Bonafide Certificate

Certified that this project report titled "Design and Development Floor Level Material Transfer Robot" is the Bonafide work of “Lalithesh K (RA2211038010007), Tejas M K (RA2211038010012) and Preetham M (RA2211038010046)” who carried out the project work under my supervision. Certified further, that to the best of my knowledge the work reported herein does not form part of any other project report or dissertation on the basis of which a degree or award was conferred on an earlier occasion on this or any other candidate.

SIGNATURE

Dr. R. Senthilnathan M.E., Ph.D.

GUIDE

Professor

Dept. of Mechatronics Engineering

Signature of the Internal Examiner

SIGNATURE

Dr. T. Muthuramalingam, M.E., Ph.D.

Professor & Head of The Department

Dept. of Mechatronics Engineering

Signature of the External Examiner

Abstract

This project presents the design and development of a floor-level material transfer robot that autonomously delivers files, documents, laboratory supplies, and other general-purpose items between staff rooms, classrooms, and laboratories on a single floor of an institutional building. The robot is built on the DANI differential-drive chassis, equipped with a stereo camera as the primary perception and localization sensor, and powered by an embedded controller with GPU capabilities wrapped under a middleware framework.

The environment is represented as an occupancy grid map, constructed by physically measuring corridor dimensions with a surveyor’s tape and rasterizing the layout into a pixel-accurate PNG where black regions encode obstacles and white regions encode traversable space. The floor map is segmented into tiles; a custom tile-switching plugin monitors the robot's position and initiates a map swap when the robot enters the overlapping region between adjacent tiles, ensuring localization continuity across the full corridor length.

Runtime localization fuses the visual-inertial positional tracking with IMU data, providing continuous pose estimates without a dedicated LiDAR sensor. Navigation is executed using SmacPlanner2D as the global path planner and the DWB (Dynamic Window B) controller as the local trajectory executor. A custom obstacle avoidance plugin extends DWB with depth-map ingestion and context-awareness, enabling the controller to consume ZED depth data and differentiate between obstacle classes during trajectory evaluation.

Obstacle avoidance is driven by the stereo camera's live depth map. To enable context-aware behavior, the ZED SDK's multiclass object detection model is applied to the RGB stream to classify detected obstacles. The stack is structured in way where when a human is identified in the robot's path, the robot stalls and waits for the person to clear, while for all other dynamic obstacles, the Nav2 global planner is triggered to replan around the blockage. This distinction ensures safe cohabitation with building occupants while maintaining delivery throughput.

Task management is handled through a web application that allows staff to submit pickup and drop-off location requests, monitor queue status, and receive delivery confirmations at each stage of the mission. The full software stack and the web backend runs on the embedded controller, with targeted memory optimization applied across the pipeline to sustain reliable operation within these constraints. This work demonstrates a practical, sensor-minimal implementation of autonomous indoor logistics for an institutional campus environment.

Acknowledgements

It has been a great honor and privilege to undergo B.Tech in Mechatronics Engineering with specialization in Robotics at SRM Institute of Science and Technology. We are very much thankful to the Department of Mechatronics, SRM Institute of Science and Technology for providing all facilities and support to meet our project requirements.

We would like to thank our Head of Department Dr. T. Muthuramalingam, M.E., Ph.D. and our project guide Dr. R. Senthilnathan M.E., Ph.D. who gave us a big helping hand during the entire project.

The success and final outcome of this project required a lot of guidance and assistance from many people, and we are extremely fortunate that we have got this all along the completion of our project work. Whatever we have achieved so far is only due to such timely guidance and assistance and we would like to thank them for their kind support.

LALITHESH K

TEJAS M K

PREETHAM M

Table of Contents

ChaPTER nO. | TITLE | | PAGE NO.
| ABSTRACT | | i
| ACKNOWLEDGEMENTS | | iii
| TABLE OF CONTENTS | | iv
| LIST OF TABLES | | vii
| LIST OF FIGURES | | viii
| LIST OF ABBREVIATIONS | | xii
| LIST OF SYMBOLS | | xv
1. | INTRODUCTION | | 1
| 1.1 | Introduction to the Broad Field of Work | 1
| 1.2 | Objectives of the Project | 5
| 1.3 | Perspective of the Project | 5
| 1.4 | Context and Motivation | 8
| 1.5 | Contribution and Significance | 10
| 1.6 | Overview of the Project | 11
| 1.7 | Notations and Conventions | 12
| 1.8 | Organization of the Report | 12
2. | Literature Survey | | 14
| 2.1 | Purposes of Survey | 14
| 2.2 | Sources of Survey | 15
| 2.3 | Review of Articles | 15
| 2.4 | Key Findings | 19
3. | System Hardware | | 22
| 3.1 | Hardware Block Diagram | 22
| 3.2 | Mechanical Design and Fabrication | 23
| 3.3 | Sensors | 29
| 3.4 | Actuators | 33
| 3.5 | Processing Unit | 35
| 3.6 | Electrical Interfaces and Communication | 36
| 3.7 | Power Supply Circuitry | 40
| 3.8 | PCB Design | 43
| 3.9 | Robot Specifications | 46
4. | System Software | | 50
| 4.1 | Software Architecture | 50
| 4.2 | Map Generation and Usage | 51
| 4.3 | Localization | 60
| 4.4 | Path Planning | 66
| 4.5 | Obstacle Avoidance | 70
| 4.6 | Control | 74
| 4.7 | Task Assignment and Management | 79
5. | System Integration | | 86
| 5.1 | Deployment Environment | 86
| 5.2 | Middleware | 89
| 5.3 | Navigation Framework | 93
| 5.4 | System Supervisor | 98
| 5.5 | Launch and Startup Configuration | 104
6. | USER INTERFACE DEVELOPMENT AND INTEGRATION | | 110
| 6.1 | Overview | 110
| 6.2 | System Architecture | 110
| 6.3 | Technology Stack | 111
| 6.4 | Interface Design and Functionality | 113
| 6.5 | Summary | 116
7. | Conclusion | | 118
| 7.1 | Conclusion | 118
| 7.2 | Scope for Future Work | 121
| REFERENCES | | xix
| APPENDIX A – SETUP GUIDE | | xxi
| APPENDIX B – DATASHEETS AND MANUALS | | xxiii

List of Tables

TABLE NO. | TITLE | PAGE NO.
TABLE 2.1 | COMPARISON OF EXISTING MAP MANAGEMENT APPROACHES WITH THE PROPOSED TILE-BASED APPROACH | 19
TABLE 3.1 | SUMMARY TABLE REPRESENTING ALL PERIPHERAL INTERFACES WITH THE JETSON NANO | 39
TABLE 3.2 | ROBOT MECHANICAL SPECIFICATIONS | 46
TABLE 3.3 | ROBOT ACTUATION SPECIFICATIONS | 47
TABLE 3.4 | ROBOT SENSING SPECIFICATIONS | 47
TABLE 3.5 | ROBOT COMPUTATION SPECIFICATIONS | 48
TABLE 3.6 | ROBOT POWER SYSTEM SPECIFICATIONS | 48
TABLE 3.7 | ROBOT ELECTRICAL INTERFACE SPECIFICATIONS | 49
TABLE 4.1 | TILE DIMENSIONS, PHYSICAL COVERAGE, AND NAVIGABLE CELL STATISTICS AT 0.04 M/PX RESOLUTION | 56
TABLE 4.2 | YAML METADATA PARAMETERS FOR EACH TILE MAP | 57
TABLE 4.3 | TILE SWITCHING ALGORITHM CONFIGURATION PARAMETERS | 58
TABLE 4.4 | VELOCITY COMMAND SOURCE PRIORITIES FOR THE PRIORITY-BASED MULTIPLEXER | 75
TABLE 4.5 | CYTRON SMARTDRIVEDUO‑30 SIMPLE SERIAL BYTE ENCODING FOR DIRECTION AND SPEED | 77
TABLE 5.1 | CYCLONEDDS COMMUNICATION MODES | 88

List of Figures

TABLE NO. | TITLE | PAGE NO.
FIGURE 1.1 | SUBSYSTEM DOMAINS AND THE INTER-DOMAIN LINKAGES THAT DEFINE THE MECHATRONICS ENGINEERING CONTRIBUTION OF THIS PROJECT | 8
FIGURE 3.1 | HARDWARE BLOCK DIAGRAM REPRESENTING THE INTERACTIONS OF DIFFERENT HARDWARE COMPONENTS WITH EACH OTHER | 22
FIGURE 3.2 | PHOTOGRAPH OF THE DANI ROBOT | 24
FIGURE 3.3 | PHOTOGRAPH OF THE BARE DANI ROBOT WILL ALL ITS ELECTRONICS STRIPPED AWAY | 24
FIGURE 3.4 | ELECTRONIC COMPONENTS REMOVED FROM THE DANI ROBOT CHASSIS | 24
FIGURE 3.5 | THE ASSEMBLED ROBOT FRAME WITH THE FOUR CARBON FIBRE CORNER COLUMNS AND ACRYLIC DELIVERY TRAY | 25
FIGURE 3.6 | THE ROBOT POSITIONED ALONGSIDE A PERSON | 25
FIGURE 3.7 | PHOTOGRAPH OF THE LOWER SHELF | 26
FIGURE 3.8 | CLOSE-UP PHOTOGRAPH OF THE DRIVE WHEEL WITH THE NEOPRENE SHEET WRAPPED | 27
FIGURE 3.9 | REAR MECANUM SUPPORT WHEEL | 27
FIGURE 3.10 | PHOTOGRAPH OF THE CAMERA MOUNT AT THE FRONT-CENTER OF THE TRAY | 28
FIGURE 3.11 | RENDER OF THE 3D-PRINTED COMPONENTS | 29
FIGURE 3.12 | PHOTOGRAPH OF THE ZED MINI CAMERA MOUNTED ON THE ROBOT (RIGHT), AND THE ZED MINI PRODUCT PHOTOGRAPH (LEFT) | 30
FIGURE 3.13 | PHOTOGRAPH OF THE TF MINI PLUS MOUNTED ON THE REAR OF THE CHASSIS | 31
FIGURE 3.14 | CLOSE-UP PHOTOGRAPH OF THE ENCODER ON THE MOTOR SHAFT | 32
FIGURE 3.15 | PHOTOGRAPH AND DATASHEET DRAWING OF THE 739530 MOTOR AND ENCODER | 33
FIGURE 3.16 | PHOTOGRAPH OF THE MDDS30 MOUNTED ON THE ELECTRONICS SHELF | 34
FIGURE 3.17 | PHOTOGRAPH OF THE EAGLE 101 CARRIER BOARD WITH THE JETSON NANO MOUNTED | 36
FIGURE 3.18 | PC817 OPTOISOLATOR (LEFT) AND TXS0108E BIDIRECTIONAL LOGIC-LEVEL SHIFTER (RIGHT) | 37
FIGURE 3.19 | PHOTOGRAPH OF THE LIPO BATTERY PACK | 40
FIGURE 3.20 | BLOCK DIAGRAM OF THE POWER DISTRIBUTION ARCHITECTURE | 42
FIGURE 3.21 | ALTIUM DESIGNER SCHEMATIC OF THE CUSTOM SIGNAL-CONDITIONING PCB | 43
FIGURE 3.22 | SINGLE-LAYER PCB LAYOUT | 44
FIGURE 3.23 | PHOTOGRAPH OF THE COMPLETED PERF-BOARD PCB | 45
FIGURE 3.24 | PHOTOGRAPH OF PCB SHOWING THE POWER LINES | 45
FIGURE 4.1 | BLOCK DIAGRAM REPRESENTING THE SOFTWARE ARCHITECTURE | 51
FIGURE 4.2 | SOLIDWORKS CAD SKETCH OF THE HI-TECH BLOCK 2ND FLOOR (DXF EXPORT). CORRIDOR OUTLINES | 53
FIGURE 4.3 | FULL FLOOR OCCUPANCY MAP AFTER ANNOTATION | 55
FIGURE 4.4 | INDIVIDUAL TESSELLATED TILE MAPS (TILE 1–5). | 56
FIGURE 4.5 | TESSELLATED MAP TILE LAYOUT WITH OVERLAP REGIONS. | 56
FIGURE 4.6 | ASYNCHRONOUS TILE SWITCH STATE MACHINE | 60
FIGURE 4.7 | RECOVERY STATE MACHINE FOR POSE-LOSS RELOCALIZATION | 65
FIGURE 4.8 | JOB LIFECYCLE STATE MACHINE | 82
FIGURE 5.1 | STARTUP DEPENDENCY CHAIN ON JETSON NANO | 108
FIGURE 6.1 | UI ARCHITECTURE | 111

List of Abbreviations

ABBREVIATION | FULL FORM/DESCRIPTION
2D | Two-Dimensional
3D | Three-Dimensional
AMCL | Adaptive Monte Carlo Localization
CAD | Computer-Aided Design
CPU | Central Processing Unit
DWB | Dynamic Window B (local trajectory controller in Nav2)
DXF | Drawing Exchange Format
GPIO | General-Purpose Input/Output
GPU | Graphics Processing Unit
IMU | Inertial Measurement Unit
LiDAR | Light Detection and Ranging
MCP | Map Change Plugin (custom tile-switching plugin)
Nav2 | Navigation 2 (ROS 2 navigation stack)
PCB | Printed Circuit Board
PNG | Portable Network Graphics
PWM | Pulse-Width Modulation
RAM | Random Access Memory
RGB | Red Green Blue (colour channels)
RGB-D | Red Green Blue Depth (colour and depth image)
RFID | Radio-Frequency Identification
ROS 2 | Robot Operating System 2
SDK | Software Development Kit
SLAM | Simultaneous Localization and Mapping
TTL | Transistor-Transistor Logic
UART | Universal Asynchronous Receiver-Transmitter
USB | Universal Serial Bus
VIO | Visual-Inertial Odometry
Wi-Fi | Wireless Fidelity (IEEE 802.11)
ZED | Zero Effort Depth (product line by Stereolabs)
ADC | Analogue-to-Digital Converter
API | Application Programming Interface
ARM64 | 64-bit ARM architecture (AArch64)
CUDA | Compute Unified Device Architecture (NVIDIA GPU programming platform)
DDS | Data Distribution Service (ROS 2 middleware transport)
DNS | Domain Name System
DWA | Dynamic Window Approach (local trajectory planner)
HTML | HyperText Markup Language
HTTP | Hypertext Transfer Protocol
HTTPS | Hypertext Transfer Protocol Secure
IP | Internet Protocol
IPC | Inter-Process Communication
JSON | JavaScript Object Notation
JST | Japan Solderless Terminal (connector standard)
NAT | Network Address Translation
ORB | Oriented FAST and Rotated BRIEF (feature descriptor)
PETG | Polyethylene Terephthalate Glycol (3D printing filament)
PGM | Portable Gray Map (occupancy grid image format)
PID | Proportional-Integral-Derivative (control algorithm)
PLA | Polylactic Acid (3D printing filament)
QR | Quick Response (code)
RMW | ROS Middleware (abstraction layer for DDS implementations)
SD | Secure Digital (memory card)
SSH | Secure Shell (remote access protocol)
SSL | Secure Sockets Layer (cryptographic protocol)
UI | User Interface
URL | Uniform Resource Locator
XML | Extensible Markup Language
YAML | YAML Ain't Markup Language (configuration file format)

List of Symbols

SYMBOL | DESCRIPTION
x | Robot position along the x-axis in the map frame (m)
y | Robot position along the y-axis in the map frame (m)
θ | Robot heading angle measured counterclockwise from x-axis (rad)
v | Linear velocity of the robot (m/s)
ω | Angular velocity of the robot (rad/s)
r | Drive wheel radius (m)
L | Wheelbase: distance between left and right drive wheels (m)
v_L | Linear velocity of the left drive wheel (m/s)
v_R | Linear velocity of the right drive wheel (m/s)
d | Obstacle distance measured by the depth sensor (m)
ρ | Map resolution (m/px)
N | Number of occupancy grid cells in a map tile (dimensionless)
p (x | z, m) | Posterior probability of robot pose x given observations z and map m
ε | Localization position error magnitude (m)
σ | Standard deviation of pose estimate uncertainty (m or rad)
t | Time (s)
Δt | Discrete time step between control updates (s)
I | Electrical current (A)
V | Voltage (V)
P | Power (W)
η | Power conversion or motor efficiency (dimensionless, 0 to 1)
b | Track width (wheelbase between left and right wheels) (m)
ωL | Angular speed of the left drive wheel (rad/s)
ωR | Angular speed of the right drive wheel (rad/s)
ω_cmd | Commanded wheel angular speed from kinematic transformation (rad/s)
ω_actual | Measured wheel angular speed from encoder (rad/s)
e(t) | Wheel speed error: ω_cmd(t) − ω_actual(t) (rad/s)
u(t) | Control output voltage applied to motor (V)
K_ff | Feedforward gain in velocity controller (dimensionless, ≈1.16)
K_p | Proportional gain in PI velocity controller
K_i | Integral gain in PI velocity controller
Δticks | Change in encoder tick count over one control interval
ticks_per_rev | Encoder counts per full wheel revolution
u, v | Pixel coordinates in the camera image plane
x_c, y_c, z_c | 3D point coordinates in the camera optical frame (m)
f_x, f_y | Horizontal and vertical focal lengths of the camera (px)
c_x, c_y | Principal point (image center) of the camera (px)
g(n) | A* exact cost from start node to node n
h(n) | A* heuristic estimate from node n to goal (Euclidean distance)
c(n, m) | Edge cost from cell n to adjacent cell m in the occupancy grid
α | Obstacle proximity cost scaling factor in A* cost function
v_max | Maximum allowable linear velocity (m/s)
ω_max | Maximum allowable angular velocity (rad/s)
T | DWB trajectory simulation time horizon (s)
w_path | DWB weight for path distance term
w_goal | DWB weight for goal distance term
w_obst | DWB weight for obstacle distance term

Chapter 1

Introduction

1.1 INTRODUCTION TO THE BROAD FIELD OF WORK

The field of autonomous indoor mobile robotics has undergone a remarkable transformation over the past decade. What was once confined to tightly controlled factory floors, automated guided vehicles following magnetic tapes or buried wire tracks, has evolved into a far broader class of systems capable of operating freely within complex, shared, and unpredictable indoor environments. Hospitals, warehouses, university campuses, corporate office buildings, and research laboratories are all active sites of deployment today, and the pace of adoption is accelerating sharply. Market analysts project the global autonomous mobile robot sector to grow from approximately USD 4.3 billion in 2023 to nearly USD 10 billion by 2032, at compound annual growth rates consistently estimated between 15% and 24% depending on the segment. This reflects a broad industrial and institutional recognition that indoor logistics, material handling, and routine transport are among the most tractable early applications of autonomous robotics in shared human environments.

The reasons for this boom are convergent. On the demand side, labor shortages in logistics and service sectors, rising operational costs, and post-pandemic pressure to reduce human contact in critical delivery workflows have pushed organizations and institutions to look for automation solutions. Hospitals have been early and consistent adopters, autonomous robots now deliver medications, laboratory specimens, and sterile supplies in hundreds of facilities worldwide, freeing clinical staff from repetitive transport duties and reducing infection-risk contact chains. Warehouses and fulfilment centers have deployed mobile robots at massive scale to handle picking, sorting, and inventory replenishment tasks that previously required large workforces. Beyond logistics, academic and institutional environments, the deployment context most directly relevant to this work present similar motivating conditions: routine, repetitive, low-stakes transport tasks between defined locations, carried out repeatedly throughout the working day, with no inherent need for human involvement.

On the supply side, a parallel set of advances has made capable indoor robots practically buildable. Depth-sensing cameras and solid-state sensor technologies have fallen in cost by orders of magnitude over the past decade, making rich environmental perception accessible at consumer and embedded hardware price points. Embedded computing platforms now provide GPU-accelerated inference and multi-core processing within the thermal and power envelope of a small circuit board. Open-source robotics middleware frameworks have matured to the point where foundational capabilities, sensor abstraction, inter-process communication, navigation pipeline architecture, are available as production-grade components ruling out the need for prototypes requiring months of custom engineering. These supply-side developments have collectively lowered the barrier to building and deploying capable mobile robots, enabling university research groups and small companies to field systems that would have required dedicated industrial engineering teams a decade earlier.

At the technical core of any autonomous mobile robot is the problem of navigation: the ability to determine the robot's position within its environment, plan a route to a given destination, and execute that route safely in the presence of other occupants and dynamic obstacles. Indoor navigation is structurally different from outdoor navigation in ways that make it non-trivially harder. Satellite-based global positioning is unavailable indoors, eliminating the simplest source of absolute position information. Indoor environments are geometrically repetitive, long uniformly tiled corridors, and open-plan spaces with few distinctive landmarks, which confound the feature-matching and loop-closure mechanisms that localization algorithms rely on. Lighting conditions vary widely across different zones and times of day, degrading the reliability of vision-based perception. And unlike outdoor spaces, indoor environments are densely shared: people move unpredictably, doors open and close, furniture is rearranged, and corridors are temporarily blocked by deliveries, cleaning equipment, or gatherings. A navigation system that works correctly in an empty building at with no crowd must continue to work correctly during its peak hours.

The dominant technical approach to indoor navigation has evolved through several generations. Early systems used infrastructure-dependent localization: The shift to infrastructure-free navigation, where the robot determines its position purely from onboard sensor data interpreted against a map of the environment, represents the defining technical advancement of the current generation of indoor mobile robots.

Two broad strategies dominate infrastructure-free indoor navigation. The first is Simultaneous Localization and Mapping, or SLAM, in which the robot builds a map of its environment in real time while simultaneously estimating its own position within that map. SLAM is appealing as it requires no prior survey of the environment, the robot can navigate a space it has never visited before, constructing its spatial model on the fly. Research in SLAM has been extraordinarily productive, producing algorithms that work from laser rangefinders, RGB-D cameras, stereo cameras, and combinations thereof, and that handle a range of environment types with increasing robustness. However, SLAM remains computationally demanding, particularly in large or geometrically ambiguous environments where data association errors, mistakenly matching observations from different locations can accumulate into substantial drift. In long, featureless corridors, the identical appearance of consecutive segments creates persistent challenges for loop closure, the mechanism by which SLAM corrects accumulated position error by recognizing previously visited places.

The second strategy is localization against a pre-built static map. Here, the environment is surveyed in advance, either by running a mapping algorithm offline or by constructing the map through direct measurement, and the resulting representation is stored as a fixed reference. During operation, the robot estimates its position by comparing live sensor observations against this stored map. This approach is generally more computationally tractable than SLAM during operation, since the map is not being modified at runtime, and it tends to produce more consistent localization behavior in familiar environments. Its limitation is inflexibility: changes to the environment that are not reflected in the stored map can degrade the localization accuracy, and the map must be re-built if the environment changes significantly.

Obstacle avoidance sits alongside localization as a core challenge of indoor navigation, and it is here that the shared nature of indoor environments introduces the most demanding requirements. Static obstacles like walls, furniture, and fixed equipment can be represented in the map and avoided through path planning. Dynamic obstacles like people, trolleys, doors, and temporarily placed objects, must be detected and responded to in real time. The distinction matters because the appropriate response to a dynamic obstacle depends not just on its presence, but on what it is: a person standing in a corridor warrants a fundamentally different robot behavior than a box left on the floor. A person is likely to move, may be startled or endangered by an aggressively replanning robot, and is subject to safety norms that a stationary box is not. This has driven significant research interest in semantically aware obstacle handling systems that use object detection and classification to identify what type of obstacle is present and select a behavior accordingly, rather than treating all dynamic obstacles as equivalent geometry to be avoided.

The sensor technologies underpinning modern indoor navigation have also diversified considerably. Laser rangefinders, long the dominant sensor for 2D indoor mapping, remain widely used for their precision and robustness across lighting conditions. Depth cameras, both structured-light and stereo-vision variants have grown substantially in deployment, offering richer 3D environmental information at lower cost and in smaller form factors. Stereo cameras in particular have attracted significant research interest because they provide both depth data for obstacle detection and RGB imagery for object recognition, enabling a single sensor to serve multiple functions within the navigation and perception pipeline. The fusion of visual data with inertial measurement unit readings, which provide high-frequency estimates of linear acceleration and angular velocity, has become a standard approach to robust state estimation: visual odometry drifts over long traversals, while IMU data captures short-timescale motion faithfully, and the combination through sensor fusion yields estimates more reliable than either source alone.

The result of these converging developments is a field that is simultaneously well-established and actively evolving. Core navigation capabilities like localization, path planning, and basic obstacle avoidance are sufficiently mature that they can be assembled from open-source components into functioning systems. The active frontier lies in making these systems robust, efficient, and deployable under real-world constraints: operating on embedded hardware with fixed compute and memory budgets, handling the full diversity of dynamic human environments, maintaining consistent performance over long operational periods, and integrating cleanly with the institutional workflows they are meant to support. It is within this context, a field past its formative research phase but still short of solved engineering that the present work situates itself, addressing the specific challenges of autonomous material transfer in a shared institutional building environment.

1.2 OBJECTIVES

The primary objective of this project is to design and develop an autonomous indoor delivery robot capable of transporting materials between the entrances of staff rooms, classrooms, and laboratories on a single floor level. The robot operates within the corridor space of the floor, navigating autonomously from a pickup point to a destination without manual intervention. The aim is to reduce the burden of routine inter-room transport on building occupants and to demonstrate a fully operational autonomous logistics platform in a busy institutional environment.

To accomplish this, the following specific tasks are to be accomplished:

- To construct an accurate spatial representation of the deployment environment and implement reliable localization using onboard sensors, enabling the robot to determine its position at all times and plan optimal paths to any designated location.
- To enable safe and reliable autonomous navigation in a shared, dynamic indoor environment. The robot must plan collision-free routes and execute them in the presence of building occupants and unpredictable obstacles. Crucially, it must respond to humans differently from other obstacles, the system must be capable of safe coexistence with people sharing the same corridors, not merely avoiding them as generic geometry.
- To develop a user-friendly interface through which building occupants can request deliveries and track mission progress in real time.

These objectives together define the scope of the system developed in this work. They span localization, map management, navigation, human-aware operation, task handling, and user interaction, the full set of capabilities required for a functionally complete indoor delivery robot operating on embedded hardware in a busy building environment.

1.3 PERSPECTIVE OF PROJECT

An autonomous indoor delivery robot is not the product of any single engineering discipline. It draws simultaneously from mechanical design, power electronics, embedded computing, computer vision, perception, localization, navigation, and control domains that each carry their own depth, their own research communities, and their own body of specialist knowledge. A computer vision researcher could spend a career advancing stereo depth estimation. An embedded systems engineer could focus entirely on optimizing real-time compute scheduling on constrained hardware. A robotics researcher could work exclusively on improving the mathematical foundations of localization algorithms. Each of these is a legitimate and substantial field of work in its own right.

The mechatronics engineer's role in a project of this kind, is fundamentally different. The goal is not to push the frontier of any one of these subsystems. It is to understand each domain well enough to make informed decisions about what to adopt, how to configure it, and critically, how to make it work with everything else. The mechatronics perspective is a systems perspective: the question of interest is not how good the perception system is in isolation, but whether the perception system produces output that the navigation stack can consume reliably, at the right rate, under the compute constraints imposed by the embedded platform, while the motors are drawing transient current loads that introduce noise into the power rail that the sensor electronics share. These are not problems that belong to any single domain. They only appear and can only be solved at the boundaries between domains.

This project spans exactly that class of problem. The mechanical platform constrains what sensors can be mounted and where, which determines the field of view available to the perception system, which in turn determines what the localization algorithm sees. The power architecture determines how much current is available to the computing hardware, which determines how much processing headroom the navigation stack has at peak motor load. The stereo camera produces depth data at a fixed resolution and frame rate, and the embedded processor must run perception, localization, navigation, communication, and control concurrently within a fixed memory budget, a constraint that requires deliberate co-design across the software stack rather than optimizing each component independently. The choice of depth-based obstacle detection connects directly to the drive controller through a software interface that must be correctly specified, timed, and handled for the robot to respond to obstacles safely. Each of these connections requires the engineer to understand both sides of the interface and to design the boundary between them with the whole system's behavior in mind.

This is the nature of mechatronics engineering as a discipline: not the depth of a specialist but the breadth and integration thinking of a systems engineer who works at the intersections. A mechanical engineer hands over a chassis; an electrical engineer hands over a power-regulated drive circuit; a software engineer hands over a navigation algorithm. The mechatronics engineer is responsible for the question that none of these individually answers: does it work as a whole? Does the chassis geometry allow the robot to turn in the corridors it will actually navigate? Does the power system remain stable when the processor is under full load, and the motors are accelerating simultaneously? Does the sensor output reach the navigation stack in time to prevent a collision? These are integration questions and answering them is the primary engineering contribution of this project.

The subsystems this project brings together span stereo vision for depth perception and object detection, visual-inertial odometry for localization, embedded GPU computing for real-time inference and navigation, differential drive actuation for motion, power electronics for stable energy distribution under variable load, and a web-based task management layer for operator interaction. The contribution is the working system, the evidence that these components, drawn from different domains, can be made to function together reliably enough to perform autonomous material delivery in a real building.

The integration of these subsystems produces a closed-loop operational architecture in which sensing, decision-making, and actuation are continuously and mutually dependent. Accurate pose estimation is contingent on consistent actuation and reliable sensor data; path planning is only as good as the pose estimate it receives; and motion execution is directly shaped by planner output. This interdependence across the mechanical, electrical, and software engineering domains is the defining characteristic of a mechatronic system as illustrated in figure 1.1, is precisely this coordinated design that enables the robot to perform autonomous delivery operations reliably within a structured indoor environment.

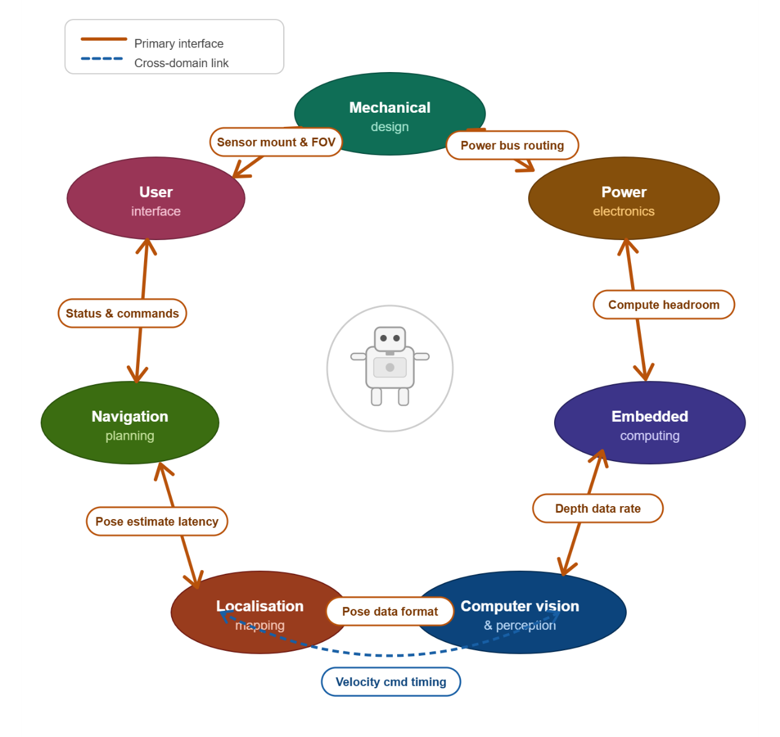
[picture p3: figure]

1.4 CONTEXT AND MOTIVATION

Figure 1.1 Subsystem domains and the inter-domain linkages that define the mechatronics engineering contribution of this project

Every engineering system is shaped as much by what it cannot do as by what it can. The floor-level material transfer robot is designed within a specific and deliberate set of operational boundaries, each of which reflects a real constraint of the deployment environment or a considered decision about where to draw the scope of the initial implementation. Understanding these boundaries is essential to understanding the design, not as limitations, but as the conditions that give the system its particular character.

Floor Level: The robot operates on a single floor of the Hi-Tech Block, navigating through corridor spaces and delivering to room entrances. It does not enter rooms, does not climb stairs, and has no elevator integration. This scope reflects the practical reality that a single floor of an institutional building already presents a complete and non-trivial navigation problem, and that confining the operational domain to a single level eliminates an entire class of complexity that would not add proportional value to the core deliverable.

Terrain: The physical environment imposes its own conditions. The corridors are flat, even, and adequately lit throughout operational hours. Flat surfaces are a prerequisite for reliable visual odometry, stereo depth estimation and pose tracking both degrade on sloped or uneven terrain where the camera's assumed ground plane diverges from reality. Adequate lighting is similarly load-bearing for the perception system: stereo vision depends on ambient illumination to extract depth, and a deployment environment with consistent lighting conditions removes a significant source of variability from the perception pipeline. Stable Wi-Fi coverage across the floor supports the communication link between the robot and the web-based task management system, ensuring that delivery requests and status updates are exchanged reliably throughout the operation.

Payload: Payload is limited to lightweight materials like files, documents, laboratory items, and similar objects within approximately one kilogram. The drive system is sized for corridor maneuvering, not load-bearing transport, and keeping payload within this range ensures the motors can achieve precise movement and controlled stopping without overloading the drivetrain or introducing torque-induced errors. Mechanical stability under load also matters for the sensor platform: an unbalanced payload shifts the robot's center of mass and can introduce vibration or tilt that degrades the quality of depth and IMU data.

Endurance: The robot runs on an onboard battery, making it fully mobile and independent of fixed power infrastructure. The tradeoff is a finite operational runtime bounded by battery capacity accepted as a practical condition of the deployment. Complete mobility and freedom from external power connections is more operationally useful than extended runtime tethered to a charging point, for a system whose task is to move freely between any two locations on the floor.

Safety: Safety in a shared environment is a non-negotiable constraint. The corridors are used by students, staff, and faculty throughout the working day, and the robot must coexist with them without creating hazards or disruptions. When a person is detected in the robot's path, the system stalls and waits for the path to clear rather than attempting to navigate around the individual. This behavior is deliberate: replanning around a moving person introduces unpredictable trajectory changes at the exact moment when predictability matters most for safety. Stalling is conservative, but it is legible, the person can see what the robot is doing and respond accordingly. For non-human obstacles such as a bag, a dustbin, or a misplaced chair, the robot replans, since these are static objects that can be routed around without the same safety considerations applying.

1.5 CONTRIBUTION AND SIGNIFICANCE

This project makes two major technical contributions to autonomous indoor navigation on embedded hardware.

The first is a pose-triggered tile-switching map management system built on top of the standard Nav2 stack and deployed on an NVIDIA Jetson Nano. Prior zone-based navigation systems trigger map transitions using external fiducial markers whose detection is unreliable under variable lighting and introduces an external dependency the robot cannot control. The system presented here uses only the robot's own real-time pose estimate to detect entry into pre-defined trigger zones and initiate an asynchronous map reload, eliminating the most commonly reported failure mode without modifying the Nav2 codebase or the deployment environment. The result is a 93.8% reduction in the active costmap footprint relative to a single full-floor occupancy grid, which is what allows the full Nav2 stack to run reliably within the Jetson Nano's 4 GB RAM constraint.
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

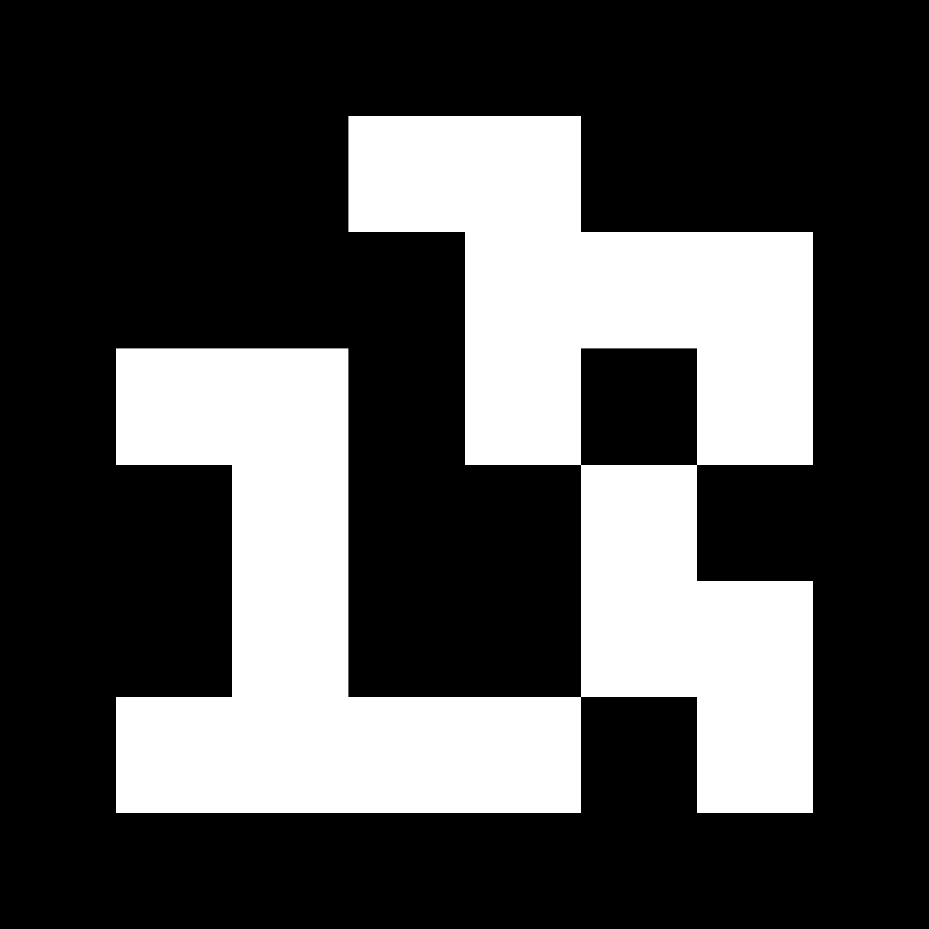
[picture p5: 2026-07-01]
CODE/ros_ws/src/zed_aruco_localization/markers/6x6_1000-8.png

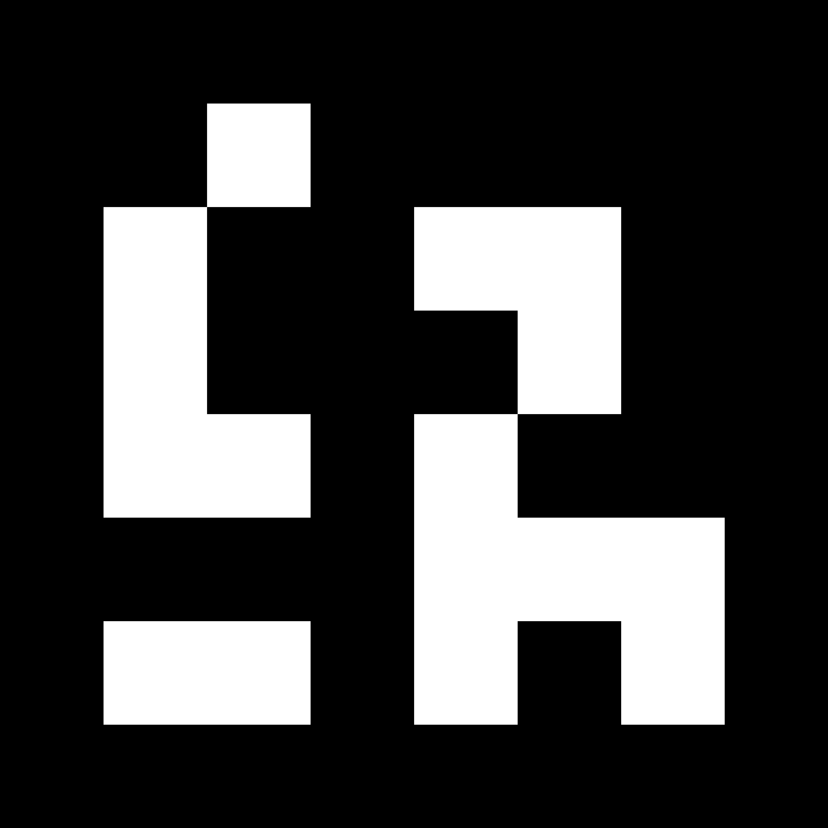
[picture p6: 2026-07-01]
CODE/ros_ws/src/zed_aruco_localization/markers/6x6_1000-6.png

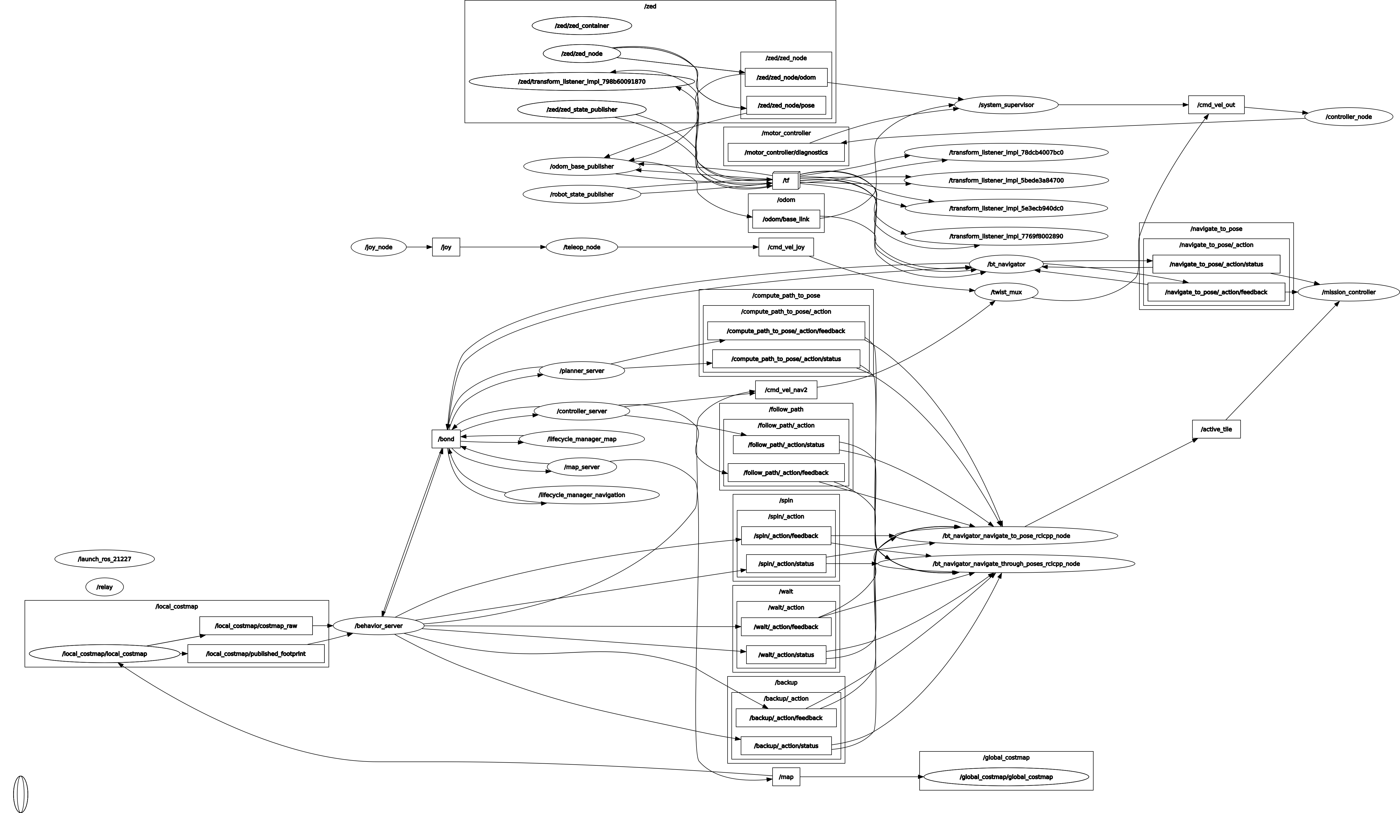
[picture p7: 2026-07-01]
TECH_DOCS/rosgraph-topic.png

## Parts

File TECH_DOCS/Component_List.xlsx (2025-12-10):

Component | Weight | Quantity | Total Weight | Price | Total Price | Source
Jetson | 141 | 1 | 141 |  |  |  | Available
ZED | 60 | 1 | 60 |  |  |  | Reviewed and Yet to be Ordered
Lidar | 200 | 1 | 200 |  |  |  | Ordered and yet to receive
Ultrasonic | 14 | 4 | 56 |  |  |  | Yet to review
Encoders |  | 2 | 0 |  |  |  | To be updated
IMU |  | 1 | 0
Carbon fiber sheet |  |  | 0
3D printing filament |  |  | 0
Buck Converter | 120 | 1 | 120 | 369 | 369 | https://robu.in/product/200w-20a-dc-dc-buck-converter-step-down-module-constant-current-led-driver-module/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
Wifi Module | 80 | 1 | 80 | 588 | 588 | https://tannatechbiz.com/tp-link-tl-wn725n-150-mbps-wireless-n-nano-usb-adapter-nano-size-wifi-dongle-compatible-with-nvidia-jetson-nano-and-raspberry-pi.html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
SD Card |  | 1 | 0 | 1479 | 1479 | https://www.amazon.in/SanDisk-Ultra%C2%AE-microSDXCTM-Warranty-Smartphones/dp/B0BDYVC5TD
DC to AC Inverter | 450 | 1 | 450 | 1299 | 1299 | https://www.amazon.in/AllExtreme-EXPINT01-Smartphones-Equipment-Electronics/dp/B0BM4M8XJB
Battery | 648 | 1 | 648 | 5115 | 5115 | https://robokits.co.in/batteries-chargers/drone-batteries/genx-power-premium-lipo-battery/genxpower-11.1v-lipo-batteries/genx-11.1v-3s-10000mah-25c-50c-premiu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
Optoisolator | 18 | 2 | 36 | 66 | 132 | https://robu.in/product/pc817-2-ch-optocoupler-isolation-module/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
Speaker | 271 | 1 | 271 | 599 | 599 | https://www.amazon.in/pTron-Bluetooth-Multi-Playback-Modes-BT5-4-Multi-Function/dp/B0DVC9J6YC
Carbon fiber tubes | 150 | 3 | 450 | 799 | 2397 | https://robu.in/product/3k-roll-wrapped-carbon-fibre-tube-hollow/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
 |  |  | 2512 |  | 9542

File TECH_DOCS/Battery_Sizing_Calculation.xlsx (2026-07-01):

 |  | Device |  |  |  | Battery
Component | Quantity | Continous Current | Peak Current | Voltage | Power | Volatge | Efficiency | Power | Current | Conversion Loss
DC to AC Inverter | 1 |  |  | 12 | 32.15 | 11.1 | 0.85 | 37.82352941 | 3.407525172 | 0.5111287758
Jetson Nano | 1 | 4 |  | 5 | 20
Speaker | 1 | 2 |  | 5 | 10
LIDAR | 1 | 0.05 |  | 5 | 0.25
Zed Mini Cam | 1 | 0.38 |  | 5 | 1.9
Drive Motors | 2 | 1.37 | 15 | 12 | 32.88 | 11.1 |  | 32.88 | 2.962162162
Buck converter | 2 |  |  | 12 | 0.925 | 11.1 | 0.97 | 0.9536082474 | 0.08591065292 | 0.002577319588
Ultrasonic | 2 | 0.015 |  | 5 | 0.15
Optoisolator | 3 | 0.005 |  | 5 | 0.075
Encoder | 2 | 0.07 |  | 5 | 0.7
 |  |  |  |  |  |  |  | Total Current | 6.455597987
 |  |  |  |  |  |  |  | With Buffer | 8.392277384
 |  |  |  |  |  |  |  | Ah | 10
 |  |  |  |  |  |  |  | C-continous Rate | 0.8392277384
 |  |  |  |  |  |  |  | C-Peak Rate | 3.243243243
 |  |  |  |  |  |  |  | Total Runtime | 0.9532573382

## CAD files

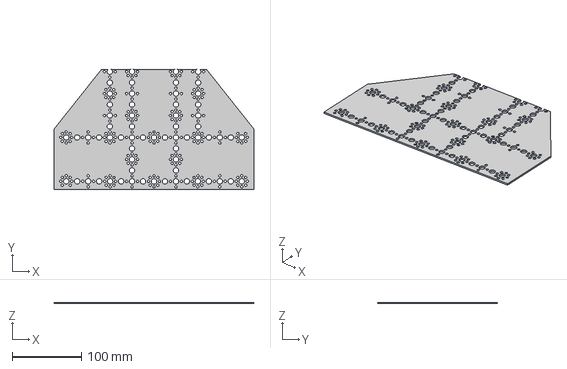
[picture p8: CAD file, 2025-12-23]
CAD/0th Stack.step
288.0 x 173.3 x 2.00 mm

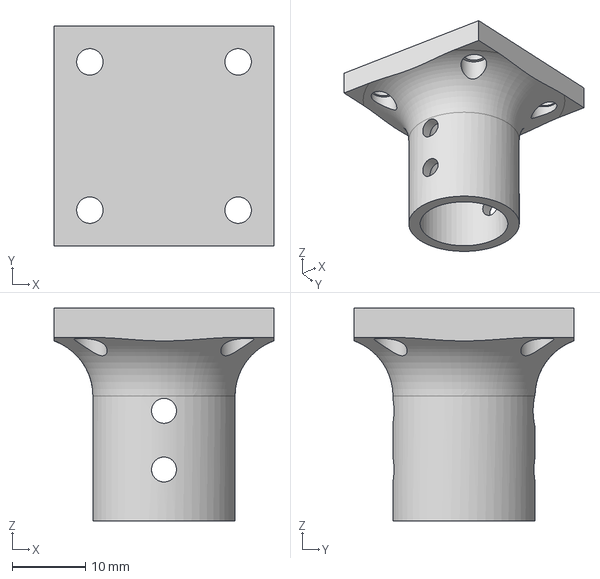
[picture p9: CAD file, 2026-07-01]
CAD/updated step/Top Tray Monut v2.step
30.0 x 30.0 x 29.0 mm

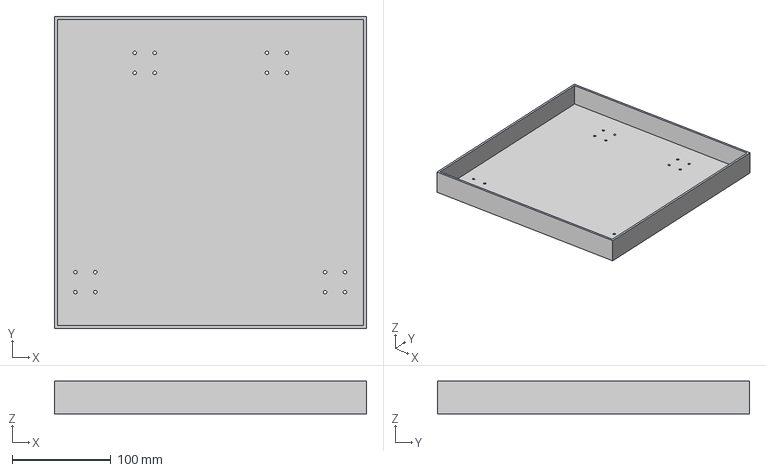
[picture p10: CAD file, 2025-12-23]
CAD/Tray.step
316.0 x 316.0 x 33.0 mm

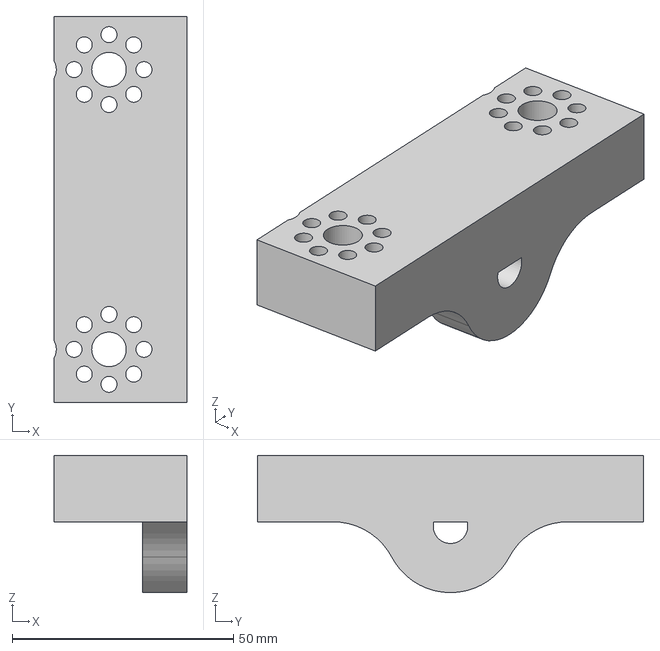
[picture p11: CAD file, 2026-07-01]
CAD/updated step/Motor Mount.step
30.0 x 87.2 x 31.0 mm

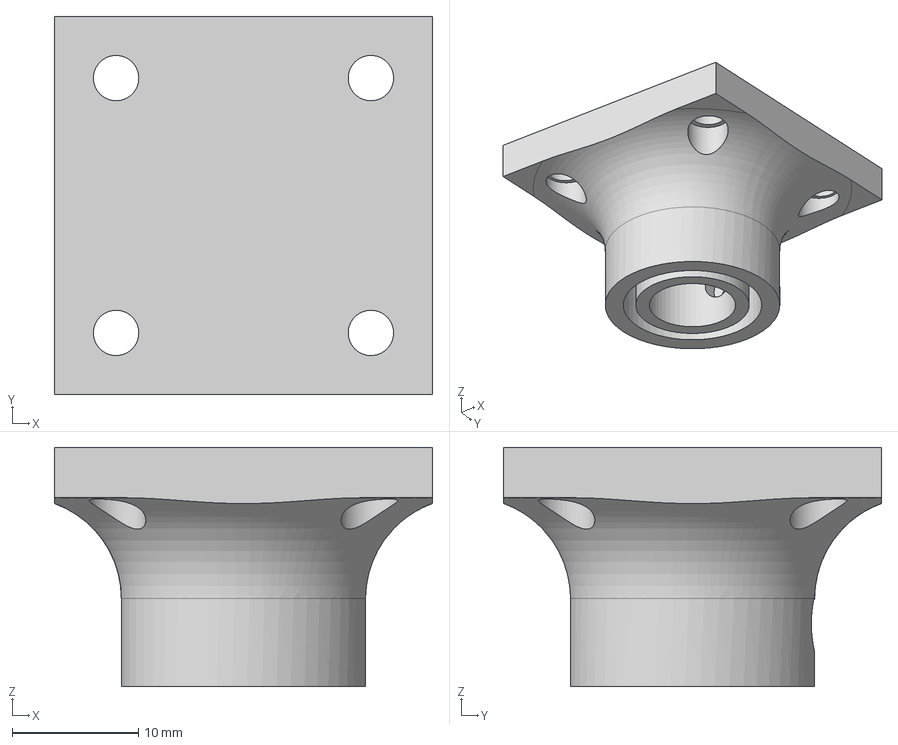
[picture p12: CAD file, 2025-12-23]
CAD/Top Tray Monut v1.step
30.0 x 30.0 x 19.0 mm

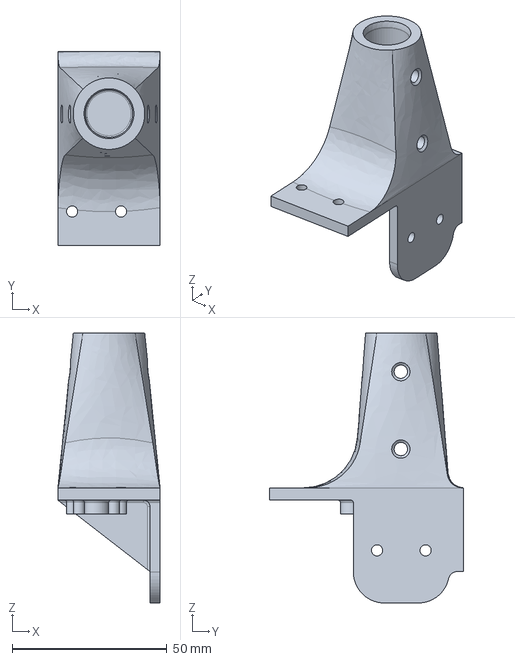
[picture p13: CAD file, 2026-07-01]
CAD/updated step/Assem1 final prj_Support structure base Front Right v2.step
33.0 x 62.5 x 87.2 mm

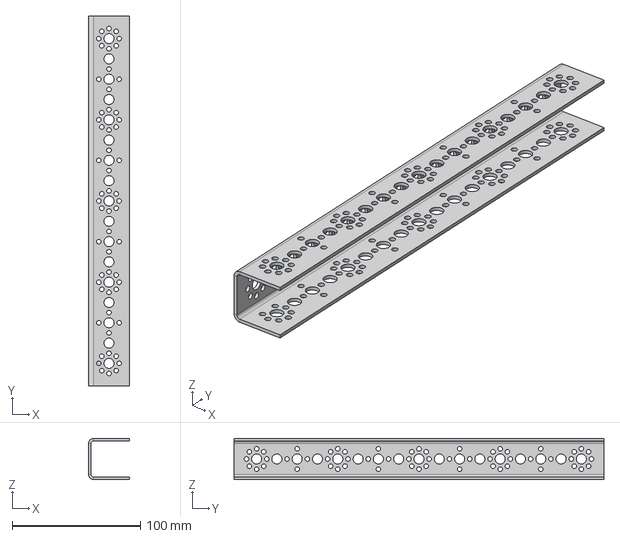
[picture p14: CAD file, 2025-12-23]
CAD/AL 28.8L Extrude.step
32.0 x 288.0 x 32.0 mm

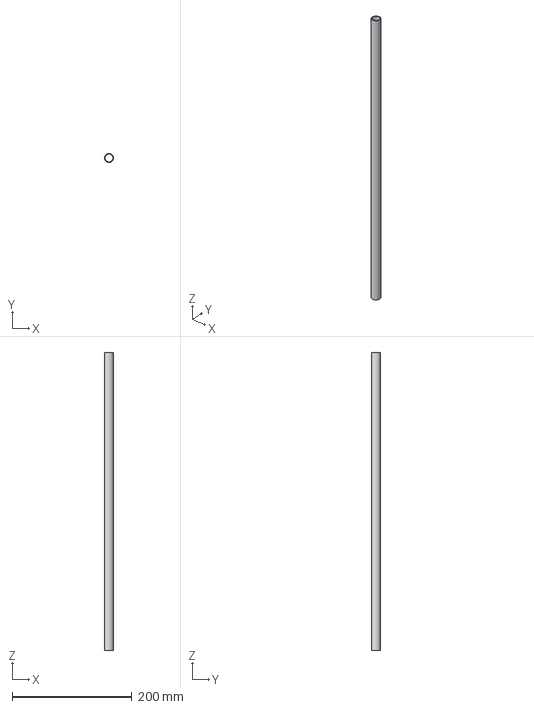
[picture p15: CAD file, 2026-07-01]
CAD/updated step/Carbon Fiber Tube 52.7cm height 15mm OD 2mm thickness v2.step
15.0 x 15.0 x 497.0 mm

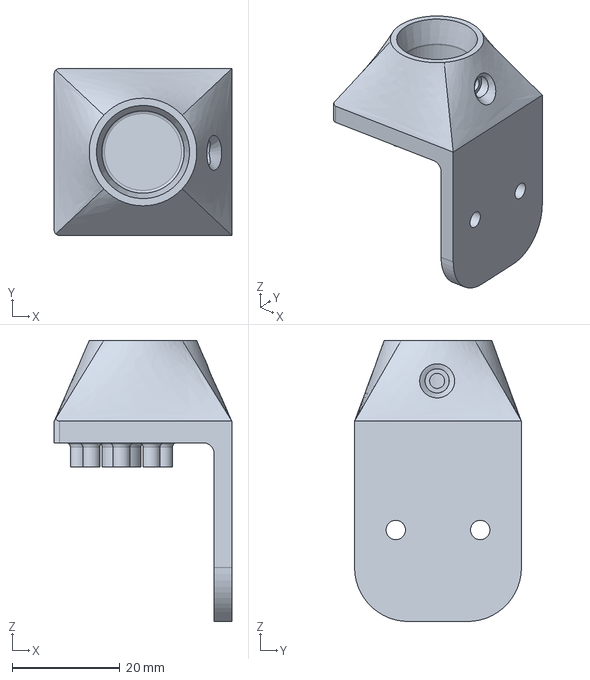
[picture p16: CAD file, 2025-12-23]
CAD/Support structure base.step
33.0 x 31.0 x 52.2 mm

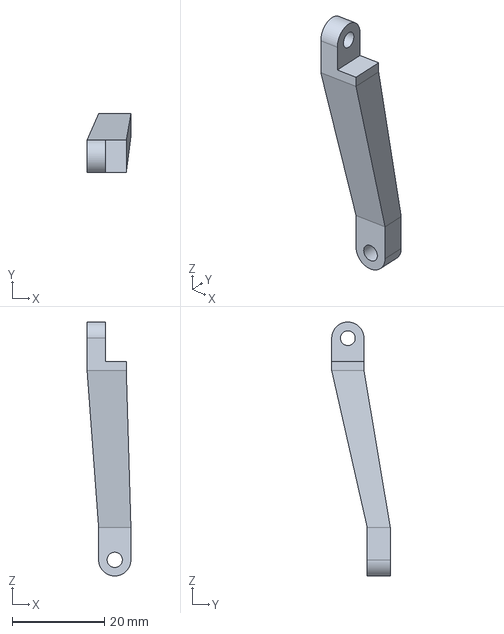
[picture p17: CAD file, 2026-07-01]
CAD/updated step/Angle Control Rod.step
9.50 x 12.7 x 55.0 mm

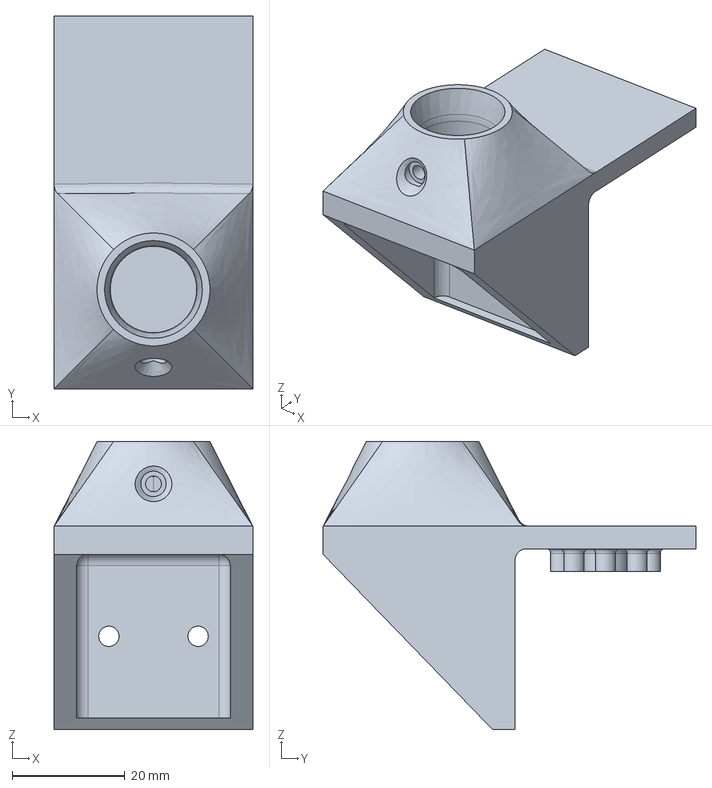
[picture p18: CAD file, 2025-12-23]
CAD/Back Support Structure Base.step
35.2 x 66.0 x 51.0 mm

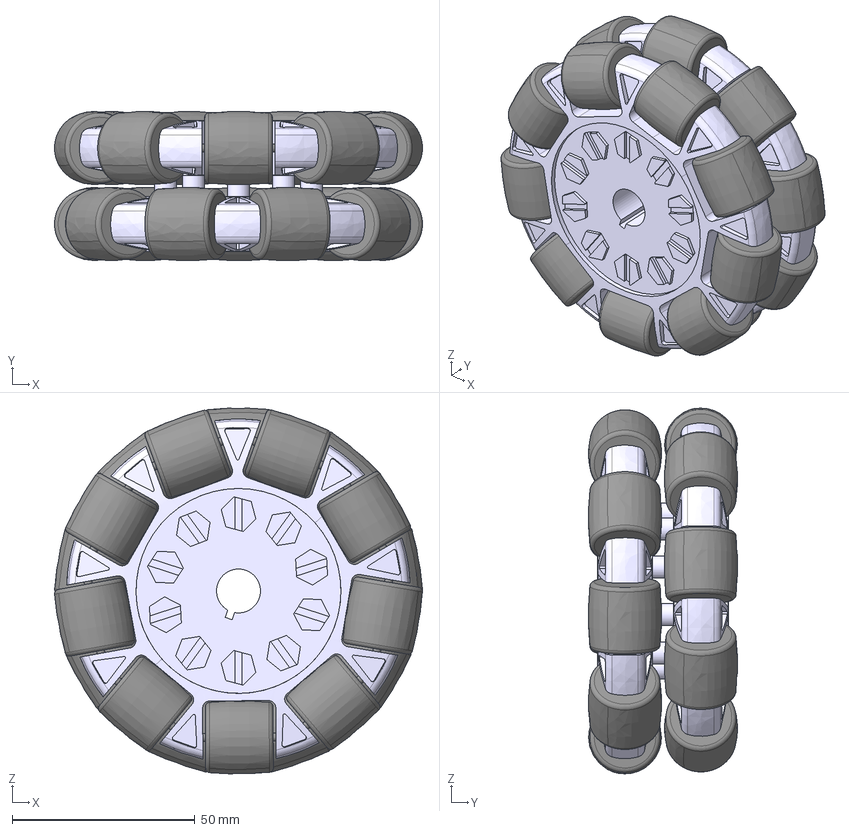
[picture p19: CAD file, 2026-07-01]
CAD/updated step/omniwheel v2.step
100.6 x 40.7 x 99.9 mm
bolt

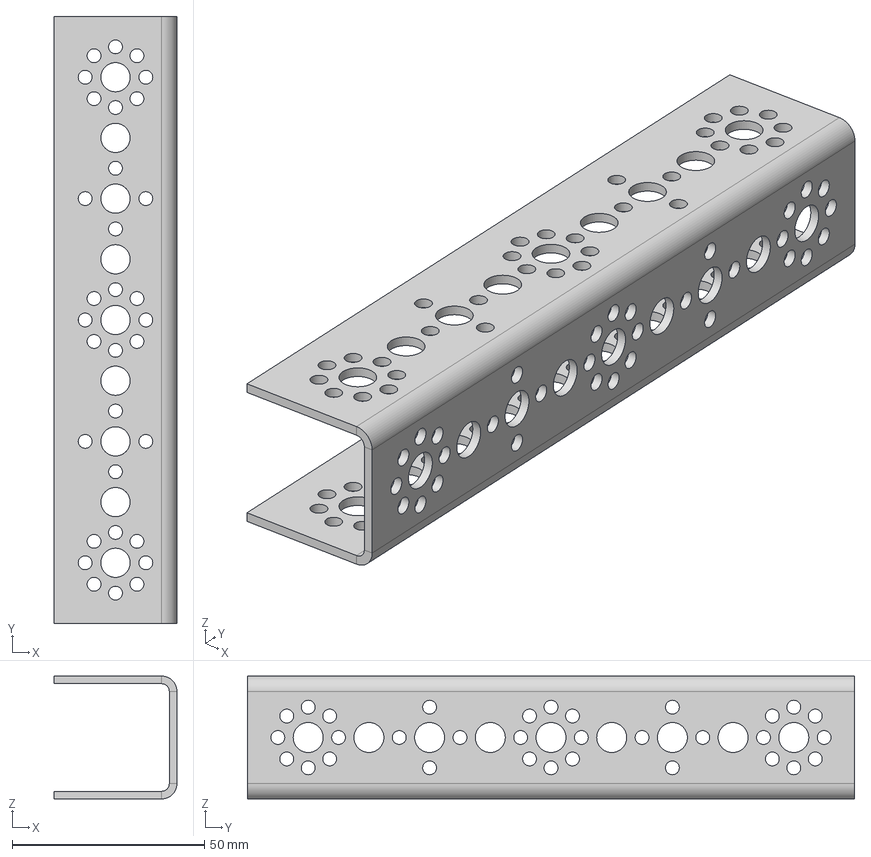
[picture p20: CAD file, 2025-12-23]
CAD/AL 15.8L Extrude.step
32.0 x 158.0 x 32.0 mm

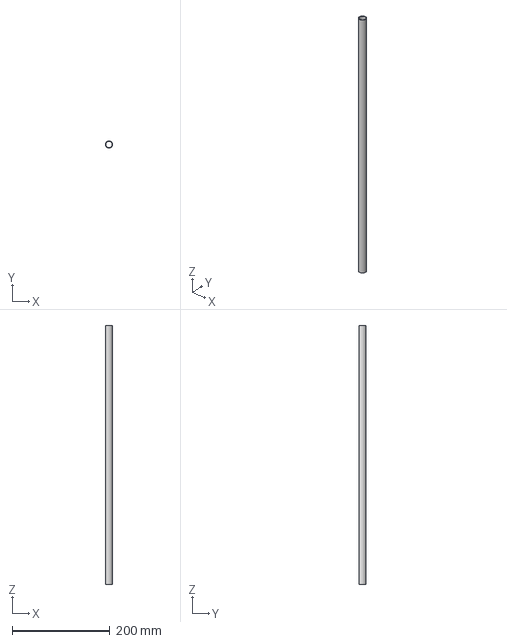
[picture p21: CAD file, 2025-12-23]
CAD/Carbon Fiber Tube 56cm length 15mm OD 1mm thickness v2.step
15.0 x 15.0 x 530.0 mm

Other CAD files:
CODE/ros_ws/src/tile_manager/maps/raw_maps/hi-tech_2nd_floor.SLDPRT
CAD/updated step/AL 28.8L Extrude.step
CAD/updated step/Carbon Fiber Tube 56cm length 15mm OD 1mm thickness v2.step
CAD/Intermediate layer mount v2.step
CAD/Assem1 final prj.f3z
CAD/Camera cross beam v1.step
CAD/Carbon Fiber Tube 52.7cm height 15mm OD 2mm thickness v2.step
CAD/Intermediate Stack.step
CAD/updated step/0th Stack.step
CAD/updated step/AL 15.8L Extrude.step.step
CAD/updated step/AL 28.8L Extrude.step.step
CAD/updated step/Assem1 final prj v25.step
CAD/updated step/Assem1 final prj_Castor Mount Back v1.step
CAD/updated step/Assem1 final prj_Support Structure Base Back Left v2.step
CAD/updated step/Assem1 final prj_Support Structure Base Back Right v2.step
CAD/updated step/Assem1 final prj_Support structure base Front Left v1.step
CAD/updated step/Cam Base Mount.step
CAD/updated step/Cam Bot Mount.step
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

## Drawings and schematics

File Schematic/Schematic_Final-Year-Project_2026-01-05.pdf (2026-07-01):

## RP-LIDAR

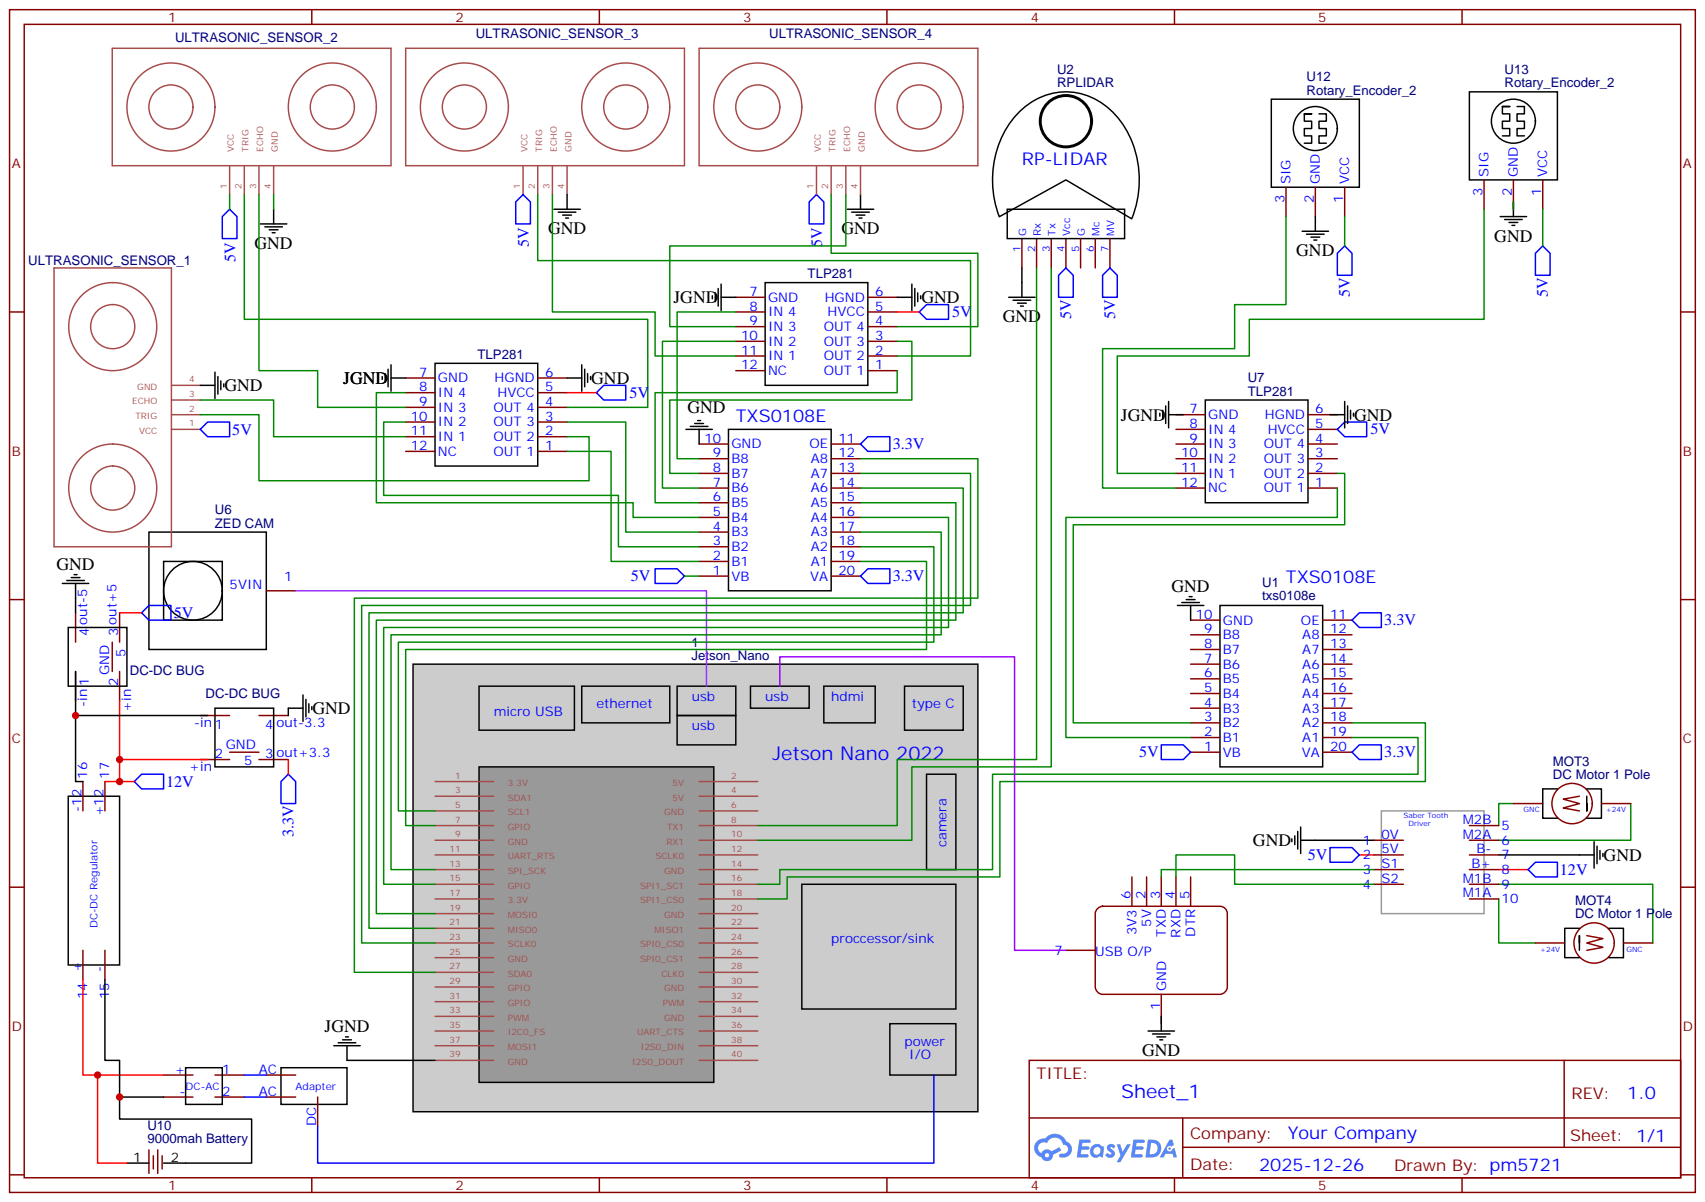
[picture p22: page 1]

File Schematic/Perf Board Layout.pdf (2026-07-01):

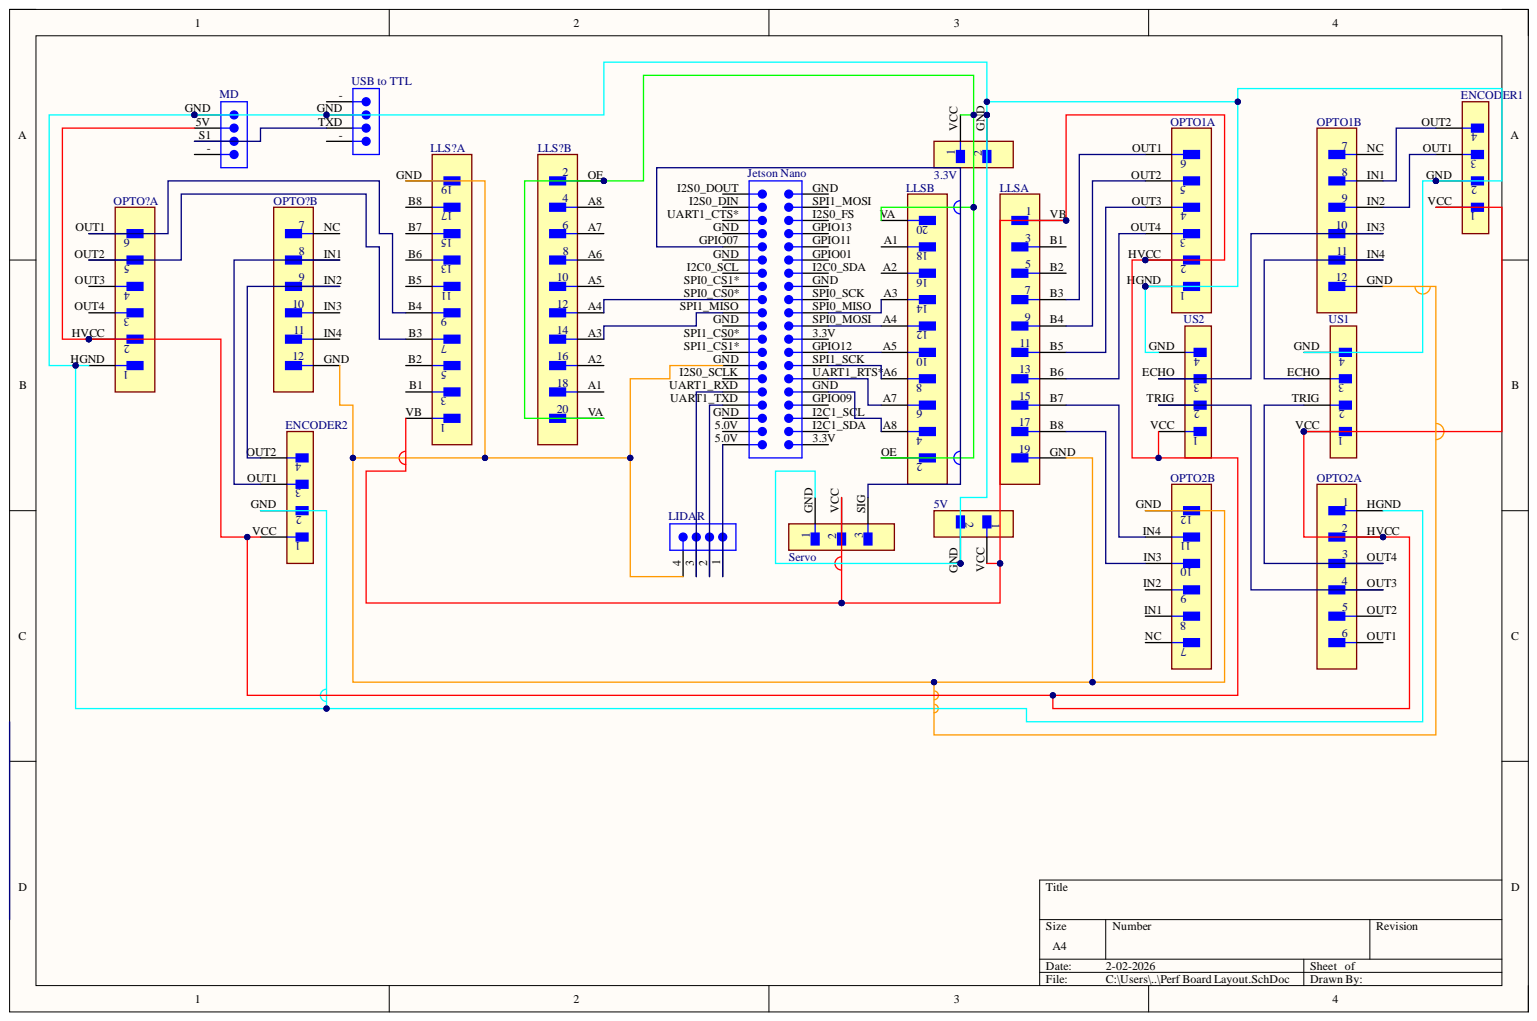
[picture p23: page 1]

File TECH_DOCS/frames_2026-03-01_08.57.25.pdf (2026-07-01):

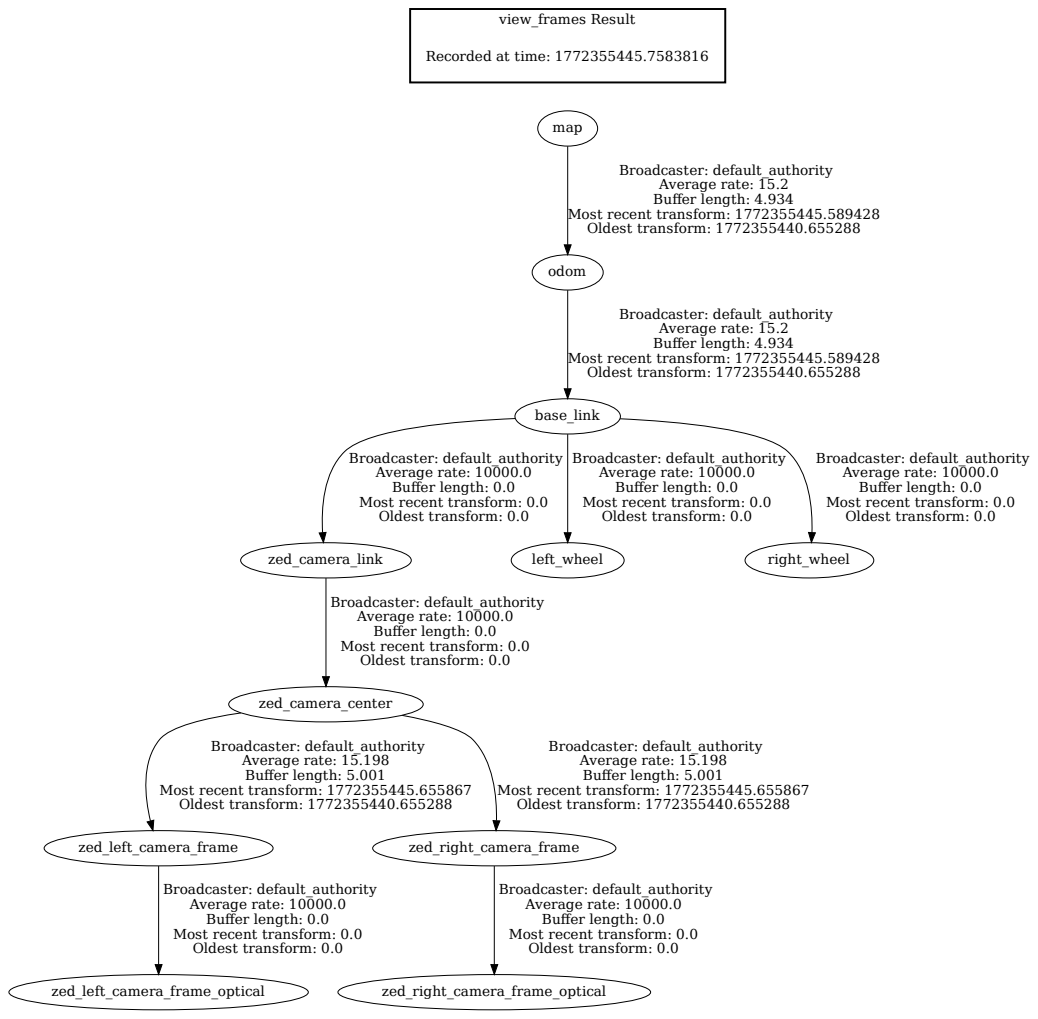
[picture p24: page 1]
view_frames Result; base_link; zed_camera_link; left_wheel; right_wheel; zed_camera_center; odom; Broadcaster: default_authority Average rate: 15.2 Buffer length: 4.934; zed_left_camera_frame; Broadcaster: default_authority Average rate: 15.198 Buffer length: 5.001; zed_right_camera_frame; zed_left_camera_frame_optical; zed_right_camera_frame_optical; map

Recorded at time: 1772355445.7583816

Most recent transform: 1772355445.589428
Oldest transform: 1772355440.655288

Broadcaster: default_authority
Average rate: 10000.0
Buffer length: 0.0
Most recent transform: 0.0
Oldest transform: 0.0

Most recent transform: 1772355445.655867

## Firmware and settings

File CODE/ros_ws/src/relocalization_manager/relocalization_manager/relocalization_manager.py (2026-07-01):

#!/usr/bin/env python3
"""
Relocalization Manager Node (v2 — with obstacle safety + search pattern)

Orchestrates ArUco-based relocalization for:
  1. Boot-time localization (robot starts at unknown position)
  2. Category 3 recovery (ZED crashed, pose lost)

State machine:
  IDLE → SPINNING → WAITING → VALIDATING → LOCALIZED
              ↓ (no marker found after 360°)
           REPOSITIONING → SPINNING (try from new position)
              ↓ (max retries)
           FAILED

Obstacle safety runs in ALL states:
  - Subscribes to ZED depth image
  - Samples center region for nearest obstacle distance
  - If obstacle < safety_distance: stop all motion, enter AVOIDING
  - AVOIDING: back up slightly, turn away, resume previous state

Publishes:
  /relocalize/status      (String)  — state name
  /relocalize/result      (String)  — JSON: {"tile": 2, "x": 1.5, ...}
  /cmd_vel_relocalize     (Twist)   — motor commands through twist_mux

Subscribes:
  /relocalize/request     (Empty)   — trigger relocalization
  /zed/zed_node/depth/depth_registered (Image) — depth for obstacle safety
  /tf                               — monitors map→base_link for ArUco

Services:
  /relocalize/trigger     (Trigger) — blocking service for supervisor
"""

import math
import json
import time
import struct

import rclpy
from rclpy.node import Node
from rclpy.qos import QoSProfile, ReliabilityPolicy, DurabilityPolicy, HistoryPolicy

from geometry_msgs.msg import Twist
from std_msgs.msg import Empty, String
from std_srvs.srv import Trigger
from sensor_msgs.msg import Image

import tf2_ros
import yaml


class RelocState:
    IDLE = "IDLE"
    SPINNING = "SPINNING"
    REPOSITIONING = "REPOSITIONING"
    AVOIDING = "AVOIDING"
    WAITING = "WAITING_FOR_CORRECTION"
    VALIDATING = "VALIDATING"
    LOCALIZED = "LOCALIZED"
    FAILED = "FAILED"


class RelocalizationManager(Node):

    def __init__(self):
        super().__init__("relocalization_manager")

        # ── Parameters ──────────────────────────────────────────────
        # Spin
        self.declare_parameter("spin_velocity", 0.3)  # rad/s
        self.declare_parameter("spin_timeout",
                               50.0)  # seconds for full 360°+ sweep
        # Repositioning
        self.declare_parameter("reposition_distance",
                               1.0)  # meters to drive between spins
        self.declare_parameter("reposition_velocity", 0.2)  # m/s forward
        self.declare_parameter("max_reposition_attempts",
                               3)  # spin-move cycles before fail
        # Correction detection
        self.declare_parameter("correction_timeout",
                               5.0)  # wait for TF stabilization
        self.declare_parameter("pose_jump_threshold",
                               0.5)  # meters for jump detection
        # Validation
        self.declare_parameter("validation_samples", 5)
        self.declare_parameter("validation_tolerance", 0.1)  # meters spread
        # Obstacle safety
        self.declare_parameter("safety_distance",
                               0.4)  # meters — stop if obstacle closer
        self.declare_parameter("critical_distance",
                               0.25)  # meters — back up immediately
        self.declare_parameter("depth_sample_width",
                               60)  # pixels — center column width to check
        self.declare_parameter("avoidance_backup_dist",
                               0.2)  # meters to back up
        self.declare_parameter("avoidance_turn_angle",
                               1.0)  # radians to turn away
        # General
        self.declare_parameter("max_retries", 3)
        self.declare_parameter("tiles_config", "")
        self.declare_parameter("cmd_rate", 10.0)

        self._spin_vel = self.get_parameter("spin_velocity").value
        self._spin_timeout = self.get_parameter("spin_timeout").value
        self._repos_dist = self.get_parameter("reposition_distance").value
        self._repos_vel = self.get_parameter("reposition_velocity").value
        self._max_repos = self.get_parameter("max_reposition_attempts").value
        self._correction_timeout = self.get_parameter(
            "correction_timeout").value
        self._jump_threshold = self.get_parameter("pose_jump_threshold").value
        self._val_samples = self.get_parameter("validation_samples").value
        self._val_tolerance = self.get_parameter("validation_tolerance").value
        self._safety_dist = self.get_parameter("safety_distance").value
        self._critical_dist = self.get_parameter("critical_distance").value
        self._depth_sample_w = self.get_parameter("depth_sample_width").value
        self._avoid_backup = self.get_parameter("avoidance_backup_dist").value
        self._avoid_turn = self.get_parameter("avoidance_turn_angle").value
        self._max_retries = self.get_parameter("max_retries").value
        self._cmd_rate = self.get_parameter("cmd_rate").value

        # ── Load tile bounds ────────────────────────────────────────
        tiles_path = self.get_parameter("tiles_config").value
        self._tiles = {}
        if tiles_path:
            try:
                with open(tiles_path) as f:
                    config = yaml.safe_load(f)
                for tid, tdata in config.get("tiles", {}).items():
                    self._tiles[int(tid)] = {
                        "bounds": tdata["bounds"],
                        "file": tdata["file"],
                    }
                self.get_logger().info(
                    f"Loaded {len(self._tiles)} tiles from {tiles_path}")
            except Exception as e:
                self.get_logger().warn(f"Could not load tiles config: {e}")

        # ── State ───────────────────────────────────────────────────
        self._state = RelocState.IDLE
        self._pre_avoid_state = None  # state to resume after avoidance
        self._retry_count = 0
        self._repos_count = 0
        self._spin_start_time = 0.0
        self._last_pose = None
        self._correction_detected = False
        self._correction_time = 0.0
        self._validation_poses = []
        self._result_tile = None
        self._result_pose = None
        # Repositioning state
        self._repos_start_pose = None
        self._repos_driven = 0.0
        # Avoidance state
        self._avoid_phase = 0  # 0=backup, 1=turn
        self._avoid_start_time = 0.0
        self._avoid_start_yaw = 0.0
        # Depth data
        self._nearest_obstacle = float("inf")
        self._depth_valid = False
        # Accumulated yaw during spin (to detect full rotation)
        self._spin_start_yaw = None
        self._spin_accumulated = 0.0
        self._spin_prev_yaw = None

        # ── TF ──────────────────────────────────────────────────────
        self._tf_buffer = tf2_ros.Buffer()
        self._tf_listener = tf2_ros.TransformListener(self._tf_buffer, self)

        # ── QoS ─────────────────────────────────────────────────────
        reliable_qos = QoSProfile(
            reliability=ReliabilityPolicy.RELIABLE,
            durability=DurabilityPolicy.VOLATILE,
            history=HistoryPolicy.KEEP_LAST,
            depth=1,
        )
        latched_qos = QoSProfile(
            reliability=ReliabilityPolicy.RELIABLE,
            durability=DurabilityPolicy.TRANSIENT_LOCAL,
            history=HistoryPolicy.KEEP_LAST,
            depth=1,
        )
        best_effort_qos = QoSProfile(
            reliability=ReliabilityPolicy.BEST_EFFORT,
            durability=DurabilityPolicy.VOLATILE,
            history=HistoryPolicy.KEEP_LAST,
            depth=1,
        )

        # ── Publishers ──────────────────────────────────────────────
        self._cmd_pub = self.create_publisher(Twist, "/cmd_vel_relocalize",
                                              reliable_qos)
        self._status_pub = self.create_publisher(String, "/relocalize/status",
                                                 latched_qos)
        self._result_pub = self.create_publisher(String, "/relocalize/result",
                                                 latched_qos)

        # ── Subscribers ─────────────────────────────────────────────
        self.create_subscription(Empty, "/relocalize/request",
                                 self._request_cb, reliable_qos)
        # Depth image for obstacle safety
        self.create_subscription(
            Image,
            "/zed/zed_node/depth/depth_registered",
            self._depth_cb,
            best_effort_qos,
        )

        # ── Service ─────────────────────────────────────────────────
        self.create_service(
            Trigger,
            "/relocalize/trigger",
            self._trigger_service_cb,
        )

        # ── Timer ───────────────────────────────────────────────────
        period = 1.0 / self._cmd_rate
        self.create_timer(period, self._tick)

        # Pre-allocate
        self._twist_msg = Twist()
        self._status_msg = String()
        self._result_msg = String()
        self._zero_twist = Twist()

        self._publish_status(RelocState.IDLE)
        self.get_logger().info(
            f"Relocalization manager v2 ready — safety_dist={self._safety_dist}m, "
            f"repos_dist={self._repos_dist}m")

    # ══════════════════════════════════════════════════════════════
    # Depth callback — obstacle safety
    # ══════════════════════════════════════════════════════════════

    def _depth_cb(self, msg: Image):
        """
        Process depth image to find nearest obstacle in front of robot.

        ZED depth is 32FC1 (float meters). We sample a narrow vertical strip
        in the center of the image — this is what's directly ahead.
        """
        try:
            if msg.encoding != "32FC1":
                return

            h = msg.height
            w = msg.width
            half_sample = self._depth_sample_w // 2

            # Center column bounds
            col_start = max(0, w // 2 - half_sample)
            col_end = min(w, w // 2 + half_sample)

            # Only check the middle third vertically (skip floor and ceiling)
            row_start = h // 3
            row_end = 2 * h // 3

            # Parse the float32 depth data
            # Each pixel is 4 bytes (float32)
            step = msg.step  # bytes per row
            min_dist = float("inf")

            # Sample every 4th row and every 4th column for speed
            for r in range(row_start, row_end, 4):
                row_offset = r * step
                for c in range(col_start, col_end, 4):
                    byte_offset = row_offset + c * 4
                    if byte_offset + 4 > len(msg.data):
                        continue
                    val = struct.unpack_from("f", msg.data, byte_offset)[0]
                    if math.isfinite(val) and 0.1 < val < min_dist:
                        min_dist = val

            self._nearest_obstacle = min_dist
            self._depth_valid = True

        except Exception as e:
            self.get_logger().debug(f"Depth processing error: {e}")
            self._depth_valid = False

    # ══════════════════════════════════════════════════════════════
    # Request handlers
    # ══════════════════════════════════════════════════════════════

    def _request_cb(self, msg: Empty):
        self._start_relocalization()

    def _trigger_service_cb(self, request, response):
        if self._state == RelocState.LOCALIZED:
            response.success = True
            response.message = f"Already localized at tile {self._result_tile}"
            return response

        if self._state not in (RelocState.IDLE, RelocState.FAILED):
            response.success = False
            response.message = f"Already in progress: {self._state}"
            return response

        self._start_relocalization()

        timeout = (self._spin_timeout * (self._max_repos + 1) *
                   (self._max_retries + 1) + 60.0)
        start = time.monotonic()
        while (time.monotonic() - start) < timeout:
            if self._state == RelocState.LOCALIZED:
                response.success = True
                response.message = json.dumps({
                    "tile":
                    self._result_tile,
                    "x":
                    round(self._result_pose[0], 3),
                    "y":
                    round(self._result_pose[1], 3),
                    "yaw":
                    round(self._result_pose[2], 3),
                })
                return response
            elif self._state == RelocState.FAILED:
                response.success = False
                response.message = "Relocalization failed"
                return response
            time.sleep(0.1)

        response.success = False
        response.message = "Timeout"
        return response

    def _start_relocalization(self):
        if self._state in (
                RelocState.SPINNING,
                RelocState.REPOSITIONING,
                RelocState.WAITING,
                RelocState.VALIDATING,
                RelocState.AVOIDING,
        ):
            self.get_logger().warn("Relocalization already in progress")
            return

        self.get_logger().info("=== RELOCALIZATION REQUESTED ===")
        self._retry_count = 0
        self._repos_count = 0
        self._correction_detected = False
        self._validation_poses = []
        self._result_tile = None
        self._result_pose = None
        self._begin_spin()

    # ══════════════════════════════════════════════════════════════
    # State transitions
    # ══════════════════════════════════════════════════════════════

    def _begin_spin(self):
        self._state = RelocState.SPINNING
        self._spin_start_time = time.monotonic()
        self._correction_detected = False
        self._last_pose = self._get_current_pose()

        # Track yaw for full rotation detection
        if self._last_pose is not None:
            self._spin_start_yaw = self._last_pose[2]
            self._spin_prev_yaw = self._last_pose[2]
        else:
            self._spin_start_yaw = None
            self._spin_prev_yaw = None
        self._spin_accumulated = 0.0

        self._publish_status(RelocState.SPINNING)
        self.get_logger().info(
            f"Spinning at {self._spin_vel:.1f} rad/s "
            f"(repos {self._repos_count}/{self._max_repos}, "
            f"retry {self._retry_count}/{self._max_retries})")

    def _begin_reposition(self):
        """Drive forward to a new position, then spin again."""
        self._repos_count += 1

        if self._repos_count > self._max_repos:
            self.get_logger().warn(
                "Max reposition attempts — retrying full cycle")
            self._retry_or_fail()
            return

        self._state = RelocState.REPOSITIONING
        self._repos_start_pose = self._get_current_pose()
        self._repos_driven = 0.0
        self._publish_status(RelocState.REPOSITIONING)
        self.get_logger().info(
            f"Repositioning: driving {self._repos_dist}m forward "
            f"(attempt {self._repos_count}/{self._max_repos})")

    def _enter_avoidance(self, reason: str):
        """Interrupt current state, handle obstacle."""
        if self._state == RelocState.AVOIDING:
            return  # already avoiding

        self._pre_avoid_state = self._state
        self._state = RelocState.AVOIDING
        self._avoid_phase = 0  # start with backup
        self._avoid_start_time = time.monotonic()

        pose = self._get_current_pose()
        self._avoid_start_yaw = pose[2] if pose else 0.0

        self._stop_motors()
        self._publish_status(RelocState.AVOIDING)
        self.get_logger().warn(f"OBSTACLE: {reason} — entering avoidance")

    def _retry_or_fail(self):
        self._retry_count += 1
        self._repos_count = 0  # reset repos counter for new retry

        if self._retry_count >= self._max_retries:
            self.get_logger().error(
                f"Relocalization FAILED after {self._max_retries} retries")
            self._state = RelocState.FAILED
            self._publish_status(RelocState.FAILED)
            self._stop_motors()
            return

        self.get_logger().info(
            f"Retrying relocalization ({self._retry_count}/{self._max_retries})"
        )
        self._spin_vel = -self._spin_vel  # reverse direction
        self._begin_spin()

    # ══════════════════════════════════════════════════════════════
    # Main tick
    # ══════════════════════════════════════════════════════════════

    def _tick(self):
        # ── Obstacle safety check (runs in ALL active states) ──
        if self._state in (RelocState.SPINNING, RelocState.REPOSITIONING):
            if self._depth_valid and self._nearest_obstacle < self._critical_dist:
                self._enter_avoidance(
                    f"critical obstacle at {self._nearest_obstacle:.2f}m")
                return

            if self._state == RelocState.REPOSITIONING:
                # During forward motion, also check safety distance (not just critical)
                if self._depth_valid and self._nearest_obstacle < self._safety_dist:
                    self._enter_avoidance(
                        f"obstacle at {self._nearest_obstacle:.2f}m during reposition"
                    )
                    return

        # ── State machine ──
        if self._state == RelocState.SPINNING:
            self._tick_spinning()
        elif self._state == RelocState.REPOSITIONING:
            self._tick_repositioning()
        elif self._state == RelocState.AVOIDING:
            self._tick_avoiding()
        elif self._state == RelocState.WAITING:
            self._tick_waiting()
        elif self._state == RelocState.VALIDATING:
            self._tick_validating()

    def _tick_spinning(self):
        now = time.monotonic()

        # Track accumulated rotation for full-360 detection
        current = self._get_current_pose()
        if current is not None and self._spin_prev_yaw is not None:
            delta_yaw = current[2] - self._spin_prev_yaw
            # Normalize to [-pi, pi]
            while delta_yaw > math.pi:
                delta_yaw -= 2 * math.pi
            while delta_yaw < -math.pi:
                delta_yaw += 2 * math.pi
            self._spin_accumulated += abs(delta_yaw)
            self._spin_prev_yaw = current[2]

        # Check if we've completed a full 360° without finding a marker
        if self._spin_accumulated > 2 * math.pi + 0.3:  # ~370° for margin
            self.get_logger().info(
                "Full rotation complete — no marker found, repositioning")
            self._stop_motors()
            self._begin_reposition()
            return

        # Safety timeout (in case yaw tracking fails)
        if now - self._spin_start_time > self._spin_timeout:
            self.get_logger().warn("Spin timeout — repositioning")
            self._stop_motors()
            self._begin_reposition()
            return

        # Send spin command
        self._twist_msg.angular.z = self._spin_vel
        self._twist_msg.linear.x = 0.0
        self._cmd_pub.publish(self._twist_msg)

        # Check for pose jump (ArUco correction)
        if current is not None and self._last_pose is not None:
            dx = current[0] - self._last_pose[0]
            dy = current[1] - self._last_pose[1]
            jump = math.sqrt(dx * dx + dy * dy)

            if jump > self._jump_threshold:
                self.get_logger().info(
                    f"Pose jump detected: {jump:.2f}m — ArUco correction received"
                )
                self._stop_motors()
                self._correction_detected = True
                self._correction_time = now
                self._state = RelocState.WAITING
                self._publish_status(RelocState.WAITING)
                return

        # Update baseline (slow blend to detect jumps)
        if current is not None:
            if self._last_pose is None:
                self._last_pose = current
            else:
                alpha = 0.05
                self._last_pose = (
                    self._last_pose[0] * (1 - alpha) + current[0] * alpha,
                    self._last_pose[1] * (1 - alpha) + current[1] * alpha,
                    current[2],
                    current[3],
                )

    def _tick_repositioning(self):
        """Drive forward reposition_distance meters, then spin again."""
        # Check if we've driven far enough
        current = self._get_current_pose()
        if current is not None and self._repos_start_pose is not None:
            dx = current[0] - self._repos_start_pose[0]
            dy = current[1] - self._repos_start_pose[1]
            self._repos_driven = math.sqrt(dx * dx + dy * dy)

        if self._repos_driven >= self._repos_dist:
            self.get_logger().info(
                f"Repositioned {self._repos_driven:.2f}m — spinning again")
            self._stop_motors()
            self._begin_spin()
            return
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

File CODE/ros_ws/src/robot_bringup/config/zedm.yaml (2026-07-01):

/zed/zed_node:
  ros__parameters:
    "":
      zed_node:
        depth:
          depth_registered:
            format: jpeg
            jpeg_quality: 95
            png_level: 3
            tiff:
              res_unit: inch
              xdpi: -1
              ydpi: -1
        left:
          image_rect_color:
            format: jpeg
            jpeg_quality: 95
            png_level: 3
            tiff:
              res_unit: inch
              xdpi: -1
              ydpi: -1
        left_gray:
          image_rect_gray:
            format: jpeg
            jpeg_quality: 95
            png_level: 3
            tiff:
              res_unit: inch
              xdpi: -1
              ydpi: -1
        left_raw:
          image_raw_color:
            format: jpeg
            jpeg_quality: 95
            png_level: 3
            tiff:
              res_unit: inch
              xdpi: -1
              ydpi: -1
        left_raw_gray:
          image_raw_gray:
            format: jpeg
            jpeg_quality: 95
            png_level: 3
            tiff:
              res_unit: inch
              xdpi: -1
              ydpi: -1
        point_cloud:
          cloud_registered:
            draco:
              attribute_mapping:
                attribute_type:
                  x: POSITION
                  y: POSITION
                  z: POSITION
                quantization_bits:
                  rgb: 16
                  x: 16
                  y: 16
                  z: 16
                rgba_tweak:
                  rgb: true
                  rgba: false
              decode_speed: 7
              deduplicate: true
              encode_method: 0
              encode_speed: 7
              expert_attribute_types: false
              expert_quantization: false
              force_quantization: false
              quantization_COLOR: 14
              quantization_GENERIC: 14
              quantization_NORMAL: 14
              quantization_POSITION: 14
              quantization_TEX_COORD: 14
            zlib:
              encode_level: 7
            zstd:
              zstd_encode_level: 7
        rgb:
          image_rect_color:
            format: jpeg
            jpeg_quality: 95
            png_level: 3
            tiff:
              res_unit: inch
              xdpi: -1
              ydpi: -1
        rgb_gray:
          image_rect_gray:
            format: jpeg
            jpeg_quality: 95
            png_level: 3
            tiff:
              res_unit: inch
              xdpi: -1
              ydpi: -1
        rgb_raw:
          image_raw_color:
            format: jpeg
            jpeg_quality: 95
            png_level: 3
            tiff:
              res_unit: inch
              xdpi: -1
              ydpi: -1
        rgb_raw_gray:
          image_raw_gray:
            format: jpeg
            jpeg_quality: 95
            png_level: 3
            tiff:
              res_unit: inch
              xdpi: -1
              ydpi: -1
        right:
          image_rect_color:
            format: jpeg
            jpeg_quality: 95
            png_level: 3
            tiff:
              res_unit: inch
              xdpi: -1
              ydpi: -1
        right_gray:
          image_rect_gray:
            format: jpeg
            jpeg_quality: 95
            png_level: 3
            tiff:
              res_unit: inch
              xdpi: -1
              ydpi: -1
        right_raw:
          image_raw_color:
            format: jpeg
            jpeg_quality: 95
            png_level: 3
            tiff:
              res_unit: inch
              xdpi: -1
              ydpi: -1
        right_raw_gray:
          image_raw_gray:
            format: jpeg
            jpeg_quality: 95
            png_level: 3
            tiff:
              res_unit: inch
              xdpi: -1
              ydpi: -1
        stereo:
          image_rect_color:
            format: jpeg
            jpeg_quality: 95
            png_level: 3
            tiff:
              res_unit: inch
              xdpi: -1
              ydpi: -1
        stereo_raw:
          image_raw_color:
            format: jpeg
            jpeg_quality: 95
            png_level: 3
            tiff:
              res_unit: inch
              xdpi: -1
              ydpi: -1
    advanced:
      thread_sched_policy: SCHED_BATCH
    body_tracking:
      allow_reduced_precision_inference: false
      body_format: BODY_38
      body_kp_selection: FULL
      bt_enabled: false
      confidence_threshold: 50.0
      enable_body_fitting: false
      enable_tracking: true
      max_range: 20.0
      minimum_keypoints_threshold: 5
      model: HUMAN_BODY_MEDIUM
      prediction_timeout_s: 0.5
    debug:
      debug_advanced: false
      debug_body_tracking: false
      debug_camera_controls: false
      debug_common: false
      debug_gnss: false
      debug_mapping: false
      debug_object_detection: false
      debug_point_cloud: false
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

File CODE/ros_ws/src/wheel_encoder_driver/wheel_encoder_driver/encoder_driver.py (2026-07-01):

#!/usr/bin/env python3
"""
Encoder Driver Node (v2 - Optimized)

Reads quadrature encoders via Jetson GPIO interrupts and publishes
wheel tick counts and velocities.

Optimizations from v1:
  - collections.deque for O(1) moving average (was O(n) list.pop(0))
  - Pre-allocated messages (reused each publish)
  - Thread-safe tick access via simple locking
  - Cached constants

Publishes:
  /encoder/ticks    (Int32MultiArray) — [left_ticks, right_ticks] raw counts
  /encoder/velocity (Float32MultiArray) — [stamp_sec, stamp_nsec, left_rad_s, right_rad_s]

Interrupt strategy:
  Channel A only (BOTH edges), read B for direction.
  204 interrupts per revolution — half the load of full quadrature.

Hardware:
  Left wheel:  board pins 19 (ch A), 21 (ch B)
  Right wheel: board pins 24 (ch A), 22 (ch B)
  Ticks per revolution: 204 (channel A, both edges)
"""

import math
import threading
from collections import deque

import rclpy
from rclpy.node import Node
from rclpy.qos import QoSProfile, ReliabilityPolicy, DurabilityPolicy
from rclpy.parameter import Parameter
from std_msgs.msg import Int32MultiArray, Float32MultiArray

try:
    import Jetson.GPIO as GPIO
    GPIO_AVAILABLE = True
except ImportError:
    GPIO_AVAILABLE = False


class EncoderDriver(Node):
    def __init__(self):
        super().__init__("encoder_driver")

        # Load and validate params
        self._declare_params()
        self._load_params()
        self._validate_params()

        # Cached constants
        self._ticks_to_rad = (2.0 * math.pi) / self._ticks_per_rev
        self._max_wheel_rad_s = 20.0  # Generous upper bound
        self._max_ticks_per_sec = self._max_wheel_rad_s / self._ticks_to_rad

        # Tick counters (updated by ISR, read by timer)
        # Use simple lock for thread safety
        self._tick_lock = threading.Lock()
        self._right_ticks = 0
        self._left_ticks = 0

        # Previous values for velocity computation
        self._prev_right_ticks = 0
        self._prev_left_ticks = 0
        self._prev_time_ns = self.get_clock().now().nanoseconds

        # Moving average buffers using deque for O(1) operations
        self._right_vel_buf = deque(maxlen=self._velocity_window)
        self._left_vel_buf = deque(maxlen=self._velocity_window)

        # Pre-allocated messages (reused each publish)
        self._ticks_msg = Int32MultiArray()
        self._ticks_msg.data = [0, 0]  # Pre-size
        self._vel_msg = Float32MultiArray()
        self._vel_msg.data = [0.0, 0.0, 0.0, 0.0]  # Pre-size

        qos = QoSProfile(
            reliability=ReliabilityPolicy.BEST_EFFORT,
            durability=DurabilityPolicy.VOLATILE,
            depth=1,
        )

        # Publishers
        self._ticks_pub = self.create_publisher(Int32MultiArray, "/encoder/ticks", qos)
        self._vel_pub = self.create_publisher(Float32MultiArray, "/encoder/velocity", qos)

        # Setup GPIO
        if not GPIO_AVAILABLE:
            self.get_logger().fatal("Jetson.GPIO not available")
            raise SystemExit(1)

        self._setup_gpio()

        # Publish timer
        period = 1.0 / self._publish_rate
        self.create_timer(period, self._publish_callback)

        self.get_logger().info(f"Encoder driver v2 started — L:{self._left_pin_a}/{self._left_pin_b} R:{self._right_pin_a}/{self._right_pin_b} TPR:{self._ticks_per_rev} rate:{self._publish_rate}Hz")

    # ==================================================================
    # Parameter handling
    # ==================================================================

    def _declare_params(self):
        self.declare_parameter("right_encoder_pin_a", Parameter.Type.INTEGER)
        self.declare_parameter("right_encoder_pin_b", Parameter.Type.INTEGER)
        self.declare_parameter("left_encoder_pin_a", Parameter.Type.INTEGER)
        self.declare_parameter("left_encoder_pin_b", Parameter.Type.INTEGER)
        self.declare_parameter("ticks_per_revolution", Parameter.Type.INTEGER)
        self.declare_parameter("wheel_radius", Parameter.Type.DOUBLE)
        self.declare_parameter("min_velocity_threshold", 0.04)
        self.declare_parameter("publish_rate", Parameter.Type.DOUBLE)
        self.declare_parameter("invert_right", False)
        self.declare_parameter("invert_left", False)
        self.declare_parameter("velocity_window", 5)

    def _load_params(self):
        self._right_pin_a = self.get_parameter("right_encoder_pin_a").value
        self._right_pin_b = self.get_parameter("right_encoder_pin_b").value
        self._left_pin_a = self.get_parameter("left_encoder_pin_a").value
        self._left_pin_b = self.get_parameter("left_encoder_pin_b").value
        self._ticks_per_rev = self.get_parameter("ticks_per_revolution").value
        self._wheel_radius = self.get_parameter("wheel_radius").value
        self._min_vel_threshold = self.get_parameter("min_velocity_threshold").value
        self._publish_rate = self.get_parameter("publish_rate").value
        self._invert_right = self.get_parameter("invert_right").value
        self._invert_left = self.get_parameter("invert_left").value
        self._velocity_window = self.get_parameter("velocity_window").value

    def _validate_params(self):
        errors = []

        for name in (
            "right_encoder_pin_a",
            "right_encoder_pin_b",
            "left_encoder_pin_a",
            "left_encoder_pin_b",
        ):
            if self.get_parameter(name).value is None:
                errors.append(f"{name} not set")

        if self._ticks_per_rev is None or self._ticks_per_rev <= 0:
            errors.append(f"ticks_per_revolution must be > 0 (got {self._ticks_per_rev})")

        if self._wheel_radius is None or self._wheel_radius <= 0:
            errors.append(f"wheel_radius must be > 0 (got {self._wheel_radius})")
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

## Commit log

2025-11-14 Battery sizing calculations and component list
    [Battery_Sizing_Calculation.xlsx, Component_List.xlsx]
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2025-12-15 ros2 map switching process
    [#hi-tech 2 floor.DXF]
2025-12-16 update tasks and schedules sheet
    [Tasks_and_Schedules.xlsx]
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2025-12-18 store stats in dir
    [stats.csv]
2025-12-18 create launch file for evaluation and enable rviz display
    [stats.csv]
2025-12-18 add marker size to csv and rename distance and angle columns
    [stats.csv]
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2025-12-19 update tasks and add start date column
    [Tasks_and_Schedules.xlsx]
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2026-01-11 Perf board layout schematic
    [Perf Board Layout.SchDoc]
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2026-01-22 fix: egl lib issue on arm
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2026-02-02 lidar connection fix
    [Perf Board Layout.SchDoc]
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2026-02-08 update raw maps folder path, add overlapping region for tile4 and updaate tile5 origin
    [hi-tech_2nd_floor.DXF, hi-tech_2nd_floor.SLDPRT]
2026-02-09 refactor campus_maps to ensure separation between tile switching and localisation
    [hi-tech_2nd_floor.DXF, hi-tech_2nd_floor.SLDPRT]
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2026-02-10 fix: switch time and map unload
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2026-02-15 fix pitch in zed to baselink transformation
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2026-02-26 fix base_link to odom frame link
    [robot.urdf.xacro]
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2026-03-01 fix wheel positions w.r.t base link
    [robot.urdf.xacro]
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2026-03-01 disable 2d mode and fix frame transformation
    [robot.urdf.xacro]
2026-03-01 fix frame linkage
    [robot.urdf.xacro]
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2026-03-01 fix minimum and maximum velocities
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2026-03-01 optimize driver, add error handling, and remove blocking actions
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2026-03-05 separate tunable parameters into config and rename package
    [controller_params.yaml]
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2026-03-05 invert angular velocity directions
2026-03-05 fix robot description package name
    [supervisor_config.yaml]
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2026-03-07 invert right wheel
2026-03-07 invert wheel directions
2026-03-07 fix: pin mapping
2026-03-07 use only channel A for interrupts and add noise filtering
    [encoder_driver.py]
2026-03-07 noise filtering
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2026-03-09 fix: switch to pid only for motor
    [supervisor_config.yaml]
2026-03-09 increase stall timeout
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2026-03-23 fix custom object detection structure
    [zedm.yaml]
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2026-03-27 fix: mount cuda runtime libs and add make symlink
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2026-03-31 fix: cudnn mount
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2026-03-31 fix: trt mount
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2026-04-01 fix: domain creation crash
    [viz_bridge.py]
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2026-04-07 fix reverse mapping, reverse limiting, and scaling
    [motor_driver.py]
2026-04-07 normalize reverse limits and clamp mixed vals
    [motor_driver.py]
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2026-04-09 avoiding killing system processes
    [supervisor_config.yaml]
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2026-04-10 fix: prevent supervisor from killing SSH and container system processes
    [supervisor_config.yaml]
2026-04-10 fix: qos profile match
    [pid_controller.py]
2026-04-10 fix: revert to default config
    [zedm.yaml]
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2026-04-11 fix: module not found error
    [relocalization_manager.py]
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2026-04-13 fix: switch turning direction
    [motor_driver.py]
2026-04-13 fix: normalization and ramping
    [motor_driver.py]
2026-04-13 fix: rotate yaw by 90
    [zedm.yaml]
2026-04-13 fix: set gravity as origin false
    [zedm.yaml]
2026-04-13 fix: frame transforms
    [robot.urdf.xacro]
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2026-04-13 fix: remap tf tree and delete odom base publisher
    [robot.urdf.xacro]
2026-04-13 fix: switch to zed odom topic
2026-04-13 fix: move block above zed
    [robot.urdf.xacro]
2026-04-14 fix: remove publish tf for zed
    [supervisor_config.yaml]
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2026-04-14 fix; floor filtering and reduced persistance lower cost
2026-04-14 fix: floor filtering
    [robot.urdf.xacro]
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2026-04-15 perf: reduce zed frame rates and update nav2 tolerance and costmap size
    [zedm.yaml]
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2026-04-17 fix: update zed initial pose
    [zedm.yaml]
2026-04-17 fix: zero out linear axes when command is angular
    [pid_controller.py]
2026-04-18 fix: fix left and right wheel motors
    [pid_controller.py]
2026-04-18 fix(nav): improve heading correction stability
    - Raise min_lookahead_dist 0.1→0.25m to prevent carrot oscillation at
    low speed during heading correction
    - Lower rotate_to_heading_min_angle 0.8→0.4rad so rotate-to-heading
    engages for a wider range, handing off to carrot closer to aligned
    - Reduce rotate_to_heading_angular_vel 0.3→0.2 rad/s to limit overshoot
    at the rotate→carrot transition
    - Drop PID ki 0.2→0.05 to reduce integral windup during sustained rotation
    - Add integral zero-crossing reset in PIDController.compute() so stale
    accumulated integral doesn't fight correction after heading overshoot
    [pid_params.yaml]
2026-04-18 fix(control): stabilize PID and heading convergence
    Encoder lag (5-sample @ 15Hz = 333ms) was 3x the PID loop period,
    causing kp=0.5 to overcorrect on every direction change and amplify
    angular commands 1.5-2x. Spin recovery was triggering repeatedly
    because RPP could never converge.
    - encoder: velocity_window 5→2 (333ms→133ms lag, below PID period)
    - pid: kp 0.5→0.1 (stable gain for 133ms encoder lag)
    - pid: feedforward_gain 1.0→0.7 (motor achieves ~70% of commanded
    velocity at low speeds; 100% ff was overdriving)
    - pid: ki 0.05 (unchanged from previous commit)
    - nav2: goal_checker stateful false→true (prevents false successes
    from momentary passes through yaw_goal_tolerance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
    [pid_params.yaml]
2026-04-18 fix(nav): reduce rotate_to_heading_angular_vel to stop bang-bang oscillation
    Lower rotate_to_heading_angular_vel from 0.2 to 0.06 rad/s to cut per-cycle
    overshoot from ~0.22 rad to ~0.006 rad — well inside yaw_goal_tolerance (0.35 rad).
    Diagnostic step to confirm RPP bang-bang is the root cause of heading oscillation.
2026-04-18 feat(nav): switch local controller from RPP to DWB
    Replace RegulatedPurePursuitController with DWBLocalPlanner to eliminate
    bang-bang heading oscillation. DWB uses proportional critic scoring
    (RotateToGoal, PathAlign, GoalAlign) so angular velocity scales with
    heading error instead of flipping between fixed ±values.
    Trajectory sampling tuned for Jetson Nano 4GB at 10 Hz:
    vx_samples=15, vtheta_samples=30, sim_time=1.5s.
2026-04-18 fix(control): increase ki and DWB PathAlign weight
    ki 0.05→0.1: right motor runs 20-30% faster during acceleration;
    higher integral gain closes the gap within ~1s instead of 2-3s.
    Zero-crossing reset prevents windup so the headroom is safe.
    PathAlign 64→96, PathDist 16→8, GoalDist 8→4: previous rebalance
    improved but didn't eliminate curving; making heading alignment
    3x dominant over forward progress should force pure rotation first.
    [pid_params.yaml]
2026-04-18 fix(nav): reduce DWB micro-corrections during path following
    forward_point_distance 0.1→0.4: looking only 10cm ahead for path
    direction caused jittery angular corrections on every grid cell kink
    in NavFn paths. 40cm lookpoint averages these out into a smooth signal.
    PathAlign 96→72: rotation-first behavior is stable, relax slightly
    so straight-path traversal isn't over-corrected.
    GoalAlign 24→8: was causing premature goal-heading turns mid-path
    before the robot reached the goal position.
2026-04-18 feat(nav): add SimpleSmoother to post-process NavFn paths
    NavFn produces grid-based staircase paths; DWB reacts to every cell
    kink with angular corrections even on straight segments. SimpleSmoother
    post-processes the path into a smooth spline before DWB follows it.
    - nav2_params.yaml: add smoother_server config + BT plugin
    - navigation.launch.py: add smoother_server lifecycle node
    - navigate_with_tiles.xml: call SmoothPath after ComputePathToPose at 1Hz
2026-04-18 fix(nav): reduce unnecessary rotation during path traversal
    RotateToGoal.lookahead_time -1→2.0: -1 means always score goal-heading
    rotation for every trajectory, causing the robot to face the final goal
    heading the entire journey instead of only near the goal.
    PathAlign 72→48: still dominant over PathDist(8)/GoalDist(4) for
    rotate-first behavior, but less aggressive during path following.
2026-04-19 fix(nav): cap max angular velocity and add Oscillation critic
    - max_vel_theta: 2.0→1.0 to prevent escalation to hard-spin
    - Add Oscillation critic (scale=1.0) to penalize sign-flip angular trajectories
    - PathAlign.scale: 48→32 to reduce correction magnitude driving escalation
    Bag analysis confirmed DWB ratcheting angular from -0.069 to -2.0 over
    4s then oscillating sign-flip; these three changes break that feedback loop.
2026-04-19 feat(nav): switch planner NavFn→SMAC2D, remove smoother_server
    NavFn A* produces grid-constrained (staircase) paths; DWB PathAlign
    detects kinks ~0.4m ahead and pre-turns, causing abrupt turns at ~1m.
    SMAC 2D (MOORE/Theta*-style) generates any-angle paths — genuinely
    straight lines on straight corridors — eliminating the kink source.
    - nav2_params.yaml: replace NavfnPlanner with SmacPlanner2D (MOORE),
    remove smoother_server section, remove nav2_smooth_path_action_bt_node
    - navigation.launch.py: remove smoother_server node and lifecycle entry
    - navigate_with_tiles.xml: remove SmoothPath + Sequence wrapper;
    SMAC 2D has internal path smoother so external pass is redundant
    Co-Author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
2026-04-21 fix: correct wheel speed asymmetry and double-scaling in motor driver
    Two bugs fixed:
    1. Proportional wheel rescaling was dead code — _normalize_wheel_velocity()
    clamped to [-1,1] before the `if max_raw > 1.0` check, so the check never
    fired. At full forward speed one wheel could be clamped while the other
    wasn't, breaking the L/R ratio. Fix: rescale raw omega values proportionally
    *before* normalization so the ratio is always preserved.
    2. _cmd_vel_callback treated incoming Twist as normalized [-1,1] and multiplied
    by max_forward/angular_speed. This was correct for joystick but wrong for the
    PID controller which outputs actual m/s — causing ~3x under-speed and
    amp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
    [motor_driver.py]
2026-04-21 feat: redesign velocity pipeline for per-wheel PID compensation
    Root cause: one motor runs faster than the other (hardware). Body-level PID
    corrects aggregate (v, w) and re-splits per wheel, so the per-motor imbalance
    is invisible at the body level.
    Fix: move pid_controller after twist_mux so it processes ALL velocity sources
    (joystick, Nav2, relocalize) identically, and publish per-wheel rad/s directly
    to motor_driver instead of reconstructing body velocity.
    pid_controller changes:
    - Subscribes to /cmd_vel_out (post-twist_mux) instead of /cmd_vel_nav2
    - Publishes Float32MultiArray /wheel_speeds [omega_l, omega_r] instead of Twist
    - Removes _wheel_to_body() round-trip and cross-axis suppre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
    [pid_params.yaml]
2026-04-21 fix: stop immediately on zero command and timeout in wheel speed controller
    Two stop-behaviour bugs:
    1. Zero command (joystick stick centred) was routed through the rate limiter,
    which took up to 0.67 s to ramp down. During that window the PID+feedforward
    actively fought deceleration, causing the robot to keep moving and overshoot.
    Fix: zero command detected in _cmd_vel_callback bypasses the rate limiter,
    immediately resets both PID integrals, and publishes [0, 0] wheel speeds.
    2. CMD_VEL timeout also used a gradual ramp + kept running _run_pid_and_publish
    during it — same fighting behaviour. Fix: on first timeout detection, stop
    immediately (same reset path as zero com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
    [pid_controller.py]
2026-04-21 feat(pid): add per-wheel independent PID gains to compensate motor asymmetry
    Left motor runs ~5-8% faster than right (confirmed by encoder tick data).
    Split kp/ki/kd/feedforward_gain into left/right variants so each wheel
    can be tuned independently. Initial values: left gets lower FF (0.65) and
    higher Ki (0.12) to resist its naturally higher speed; right gets higher
    FF (0.75) and lower Ki (0.08) to push the slower motor harder.
    Debug topic expanded from 28 to 31 floats to expose per-wheel gains.
    [pid_params.yaml]
2026-04-21 feat(tools): add real-time PID tuning plotter
    Live matplotlib plotter subscribing to /pid/debug. Shows 4 panels:
    desired vs actual wheel speeds, per-wheel error, PID term decomposition
    (FF/P/I/D per wheel), and body-space tracking errors. Rolling window
    configurable via --window arg (default 15 s).
    ros2 run diff_drive_controller pid_plotter
    ros2 run diff_drive_controller pid_plotter --ros-args -p window:=30
2026-04-21 fix(motor_driver): send serial stop immediately on zero wheel speeds
    The control loop fires every 100 ms. Previously a zero command from
    pid_controller would sit in _omega_*_target until the next timer tick
    before the Sabertooth was told to stop, causing a perceptible ramp-down
    delay. Now _wheel_speeds_callback calls _send_stop() directly when both
    targets are zero, so the hardware stop is sent within the message
    delivery latency (~1 ms) rather than up to 100 ms later.
    [motor_driver.py]
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2026-04-21 fix: camera tilt
    [robot.urdf.xacro]
2026-04-22 fix: tf lookup to include camera mount
2026-04-22 fix: camera mount child of base link
    [robot.urdf.xacro]
2026-04-22 fix: remove left cam frame lookup
2026-04-22 fix: correct aruco marker orientation signs and base_to_body tf direction
    All marker roll/pitch values in aruco_loc.yaml were inverted — OpenCV
    defines marker Z as pointing toward the camera (out of wall face), but
    the YAML had them pointing into the wall, mirroring the computed robot
    pose through every marker plane and placing the robot outside the map.
    Also fixed _base_to_body lookup: was lookupTransform("zed_camera_link",
    "base_link") giving T_{body←base}, but the chain requires T_{base←body}
    = lookupTransform("base_link", "zed_camera_link").
2026-04-24 fix: update cam angle
    [robot.urdf.xacro]
2026-04-24 fix(zed_aruco_localization): use absolute path remapping for camera_info topic
    image_transport::create_camera_subscription internally derives the camera_info
    topic as an absolute path (/zed/in/camera_info), which doesn't match the
    relative remapping rule. Switch to an absolute path remapping so the subscription
    correctly resolves to /zed/zed_node/rgb/camera_info and eliminates the
    image/camera_info synchronization warning.
2026-04-24 fix(zed_aruco_localization): hardcode ZED topic path to fix camera_info sync
    message_filters::Subscriber (used internally by image_transport CameraSubscriber)
    does not apply ROS2 topic remappings, so the camera_info topic was always resolved
    literally as /zed/in/camera_info regardless of launch remappings.
    Fix by subscribing directly to "zed_node/rgb/image_rect_color" so image_transport
    derives camera_info as "zed_node/rgb/camera_info", which resolves with the /zed
    namespace to the correct ZED topic /zed/zed_node/rgb/camera_info. Remove the now
    unnecessary image and camera_info remappings from the launch file.
2026-04-24 temprorily deisable obstacle avoidance and aruco
    [supervisor_config.yaml, zedm.yaml]
2026-04-25 fix(nav2): prevent false-positive goal success when goal is within local costmap
    Lower trans_stopped_velocity/rot_stopped_velocity from 0.25 to 0.05 so DWB
    does not treat a still-moving robot as stopped. Tighten xy_goal_tolerance from
    0.3 m to 0.15 m in both goal checker and DWB. Raise min_x/theta_velocity_threshold
    from 0.001 to 0.05 so Nav2 suppresses goal-checking while the robot is actively
    commanded to move.
2026-04-25 fix: left and right
    [motor_driver.py]
2026-04-25 fix: update cam tilt
    [robot.urdf.xacro]
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2026-04-26 fix(diff_drive): move left/right inversion to kinematics for correct PID coupling
    The motor cables are physically wired opposite (left Sabertooth port drives
    right wheel and vice versa). The previous fix (commit 945fe57) patched this
    at the motor_driver output level by swapping wheel_speeds indices, but that
    cross-coupled the PID feedback loops — each PID was measuring one physical
    wheel while controlling the other, causing asymmetric wheel speeds during
    in-place rotation.
    Fix: invert the angular velocity sign in _body_to_wheel (pid_controller) and
    restore the correct index assignment in motor_driver. Net turning direction
    for Nav2 is unchanged, but each PID now owns its physical wheel en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
    [motor_driver.py, pid_controller.py]
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2026-04-26 fix(diff_drive): fix encoder sign, FF gains, and wheel_to_body inverse
    Three bugs causing asymmetric wheel speeds during rotation:
    1. encoder_params: invert_right=true — right encoder A/B phasing reports
    positive ticks when the wheel spins backward; inversion corrects the
    sign so actual_right_vel matches the negative desired during rotation.
    2. pid_params: swap feedforward gains — gains were calibrated before the
    motor cable swap was moved into kinematics (commit 5bbaa92), so they
    were being applied to the wrong physical motors. Left port drives the
    physically slower wheel (needs higher FF=1.17); right port drives the
    faster wheel (lower FF=1.15).
    3. pid_controller: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
    [pid_params.yaml]
2026-04-26 tune: increase PID gains to correct forward/backward motor asymmetry
    Motors are more efficient in the forward direction, causing the
    forward-going wheel to consistently outrun the backward-going wheel
    during rotation. The PID integral lacked authority to correct this:
    max correction was only Ki * max_integral = 0.08 * 2.0 = 0.16 rad/s.
    Raise gains to give the integral enough room to close the gap:
    kp: 0.10 → 0.20 (faster proportional response)
    ki: 0.08 → 0.15 (faster integral accumulation)
    max_integral: 2.0 → 3.0 (max correction now 0.45 rad/s)
    kd: unchanged at 0.07
    Also fix min_linear_vel: -0.1 → -0.5 to match the symmetric
    forward/backward limit (was unnecessarily rest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
    [pid_params.yaml]
2026-04-26 fix: keep only feedforward and separate rotation gain
    [pid_params.yaml]
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2026-04-26 fix motor dead zone
    [motor_driver.py]
2026-04-26 fix: simplify motor driver for debugging
    [motor_driver.py]
2026-04-26 fix: add missing arg
    [motor_driver.py]
2026-04-26 invert left wheel dir
    [motor_driver.py]
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2026-04-26 fix: signal supervisor to boot nav stack when job starts
    job_manager never set _nav_needed=True, so supervisor stayed in IDLE
    forever. Set it when entering WAITING_FOR_NAV so the 1Hz publisher
    broadcasts True on /system/nav_needed and supervisor transitions to
    ACTIVATING.
2026-04-26 fix: widen inflation radius to stop path hugging walls
    inflation_radius 0.15→0.55 and cost_scaling_factor 10→3 (global+local).
    The tiny 3-cell gradient gave SmacPlanner2D nothing to steer through;
    cost_travel_multiplier had no gradient to act on so paths sat at the bubble edge.
2026-04-26 fix: reduce smoother corner cutting and delay early turning
    w_smooth 0.3→0.1 and w_data 0.2→0.4 so SmacPlanner2D smoother stops
    pulling the path through corners. PathAlign forward_point_distance 0.5→0.3
    so DWB doesn't start rotating 0.5m before the corner is reached.
    Fixes robot exiting costmap due to premature turn at junction.
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2026-04-26 fix: return home after job completion and fix resume_job crash
    - Call _return_home() after every job finishes so the robot navigates
    back to the home position when the queue is empty
    - Replace undefined _resume_job() call with _execute_job() to prevent
    AttributeError when recovering an interrupted job (_execute_job
    already handles the interrupted flag internally)
2026-04-26 fix: correct nav2 params causing false early goal success
    Three fixes for DWB/goal-checker false positives on distant goals:
    1. acc_lim_theta 0.15→1.2, decel_lim_theta -0.15→-1.2: the 0.15 value
    was a copy-paste of the linear limit; with it DWB could only reach
    0.525 rad/s in sim_time, making most angular samples infeasible and
    causing RotateToGoal to fire prematurely far from the goal.
    Also restores vtheta_samples 20→30 now that the full angular range
    is reachable.
    2. stateful: false: prevents check_xy_ being permanently disabled after
    the robot passes through a waypoint/switch-point en route, which
    allowed yaw-only goal checking for the rest of the navigation r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
2026-04-29 fix: remove dependents for zed
    [supervisor_config.yaml]
2026-04-29 fix: eliminate double job execution race and nav2 config inconsistencies
    Remove redundant _execute_job thread spawns from _restore_state and
    _handle_delivery_request — _job_executor is now the sole executor,
    preventing concurrent double-execution on the same job object.
    Fix nav2_params: remove xy_goal_tolerance/trans_stopped_velocity/
    rot_stopped_velocity from DWB FollowPath block (SimpleGoalChecker is
    the sole authority); correct default_nav_to_pose_bt_xml to match the
    actual BT file in use (navigate_with_tiles.xml).
2026-04-30 fix: route human-blocking stop to /cmd_vel_estop and tighten TF tolerances
    WaitUntilHumanClears was publishing zero-velocity to /cmd_vel — a topic
    nothing in the pipeline subscribes to. The motor pipeline expects
    /cmd_vel_nav2 (Nav2) or /cmd_vel_estop (highest-priority twist_mux input).
    Route safety stops to /cmd_vel_estop so the robot actually halts when a
    human blocks the path.
    Tighten TF freshness in nav2_params: transform_timeout 2.0→0.5 (bt_navigator)
    and FollowPath.transform_tolerance 1.0→0.2. At 15Hz ZED publish + 10Hz
    controller, the prior values allowed up to 1s-stale TF lookups, which
    let goal_checker fire on stale pose snapshots.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
2026-04-30 fix: WaitUntilHumanClears returns FAILURE on clear, route stop to /cmd_vel_nav2
    Two real bugs in the human-aware navigation path:
    1. WaitUntilHumanClears returned SUCCESS when the human cleared. With the
    BT structure (Inverter wrapping a Sequence of HumanBlockingPath +
    WaitUntilHumanClears), SUCCESS propagated as Sequence SUCCESS → Inverter
    FAILURE → ReactiveSequence FAILURE → RecoveryNode triggered. The robot
    ran ClearCostmap/Spin/BackUp instead of resuming navigation. Recovery
    actions displaced the robot, replans truncated the path, and goal_checker
    could fire on a shortened path — explaining "moves a bit, then succeeds".
    Returning FAILURE flips through the In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
2026-04-30 fix: apply ros-code-reviewer findings across tile_manager and depth_obstacle_layer
    Critical / Major (C++):
    - depth_obstacle_layer: clone() instead of shallow cv::Mat copy (use-after-free)
    - depth_obstacle_layer: clamp max_i/max_j to size-1 to prevent memset overwrite
    - depth_obstacle_layer: protect cam_model_ with depth_mutex_ in cameraInfoCallback
    and capture cx/cy/fx_inv/fy_inv inside lock in updateCosts
    - depth_obstacle_layer: filter humanCallback to Person label only
    - BT nodes: replace rogue rclcpp::Node::make_shared with shared blackboard node;
    remove spin_some() from tick()/onRunning()
    - BT nodes: filter humanCallback to Person label only
    - WaitUntilHumanClears: TF failure returns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
2026-04-30 fix: watchdog timeout log as info
    [motor_driver.py]
2026-04-30 fix: update log level
    [motor_driver.py]
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2026-05-01 fix: stop robot replanning around humans — fix humanCallback clear-on-empty bug + migrate BT params to nav2_params.yaml
    Root cause: humanCallback in all three subscribers (depth_obstacle_layer,
    HumanBlockingPath, WaitUntilHumanClears) called clear() on every ZED message,
    including frames with no detected persons. Brief ZED detection misses wiped
    human bboxes/positions, exposing humans to the costmap and triggering Nav2
    path replanning around them instead of the BT stop+alarm path.
    Fix:
    - Skip clear+rebuild when no persons present; let removeStaleHumans() handle
    expiry in the costmap layer (already uses per-bbox timestamps).
    - BT nodes add persistence window: detections preserved for hum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
